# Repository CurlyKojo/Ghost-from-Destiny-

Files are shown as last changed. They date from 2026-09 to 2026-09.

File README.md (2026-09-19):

ghost

#Ghost from Destiny — a 3D-printed voice companion

A desk-sized Ghost that listens for "Hey Ghost", talks back in character, animates its eye, glows, and looks around. Alexa-shaped idea, Ghost-shaped personality.

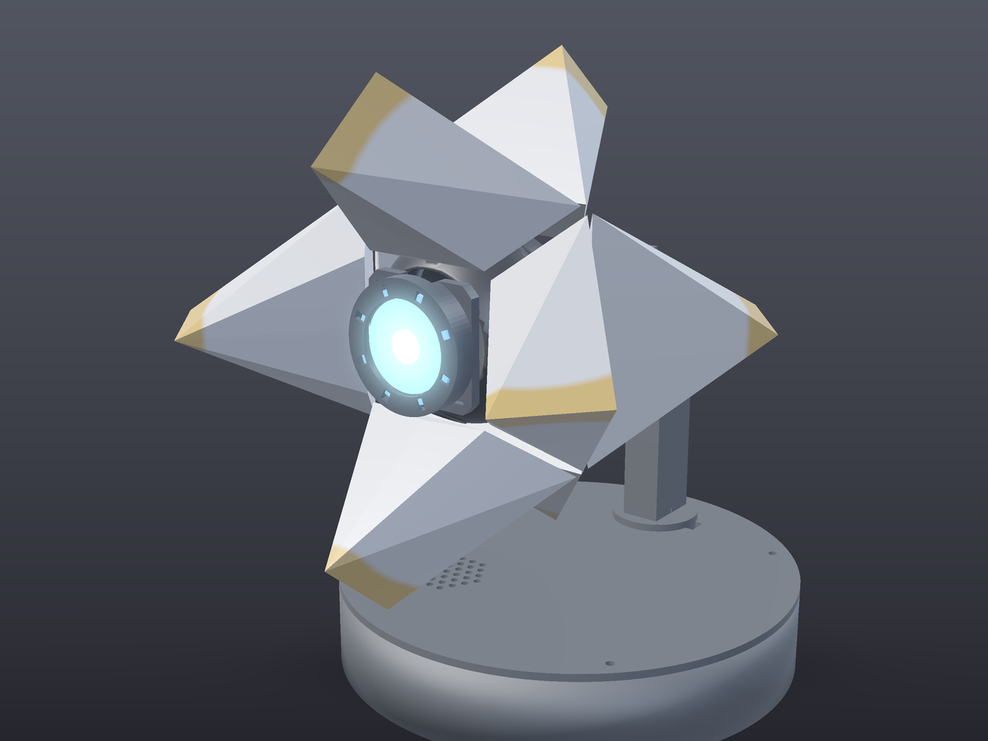
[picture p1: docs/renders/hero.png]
hero


The shell is built straight from the Bungie reference sheet: the same 8 pieces, the diamond with its X seams from the front, the X with blunt arm ends from the side, the central diamond and notches from the top.

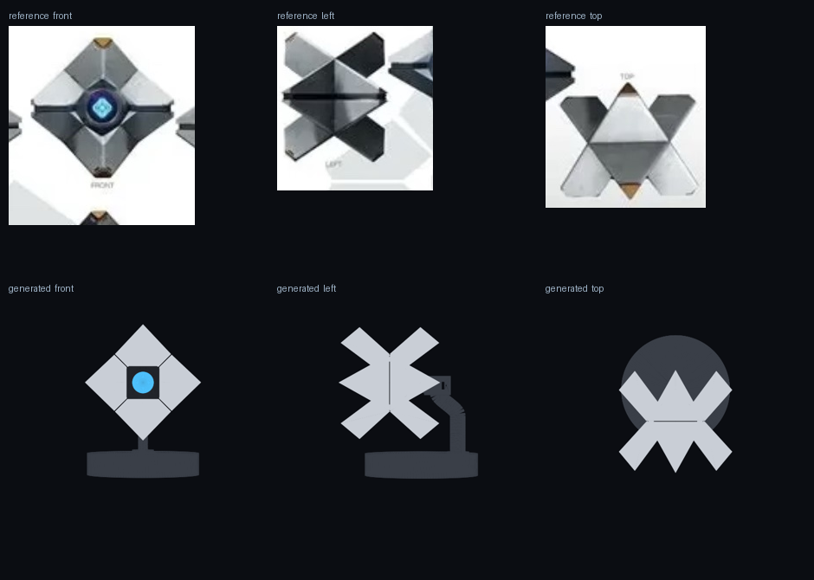
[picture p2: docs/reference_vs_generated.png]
reference vs generated


The shell opens: each piece rides a spring-loaded pin in the core, eight tendons meet at a ring on the eye axis, and a Bowden cable to a servo in the base pulls them shut.

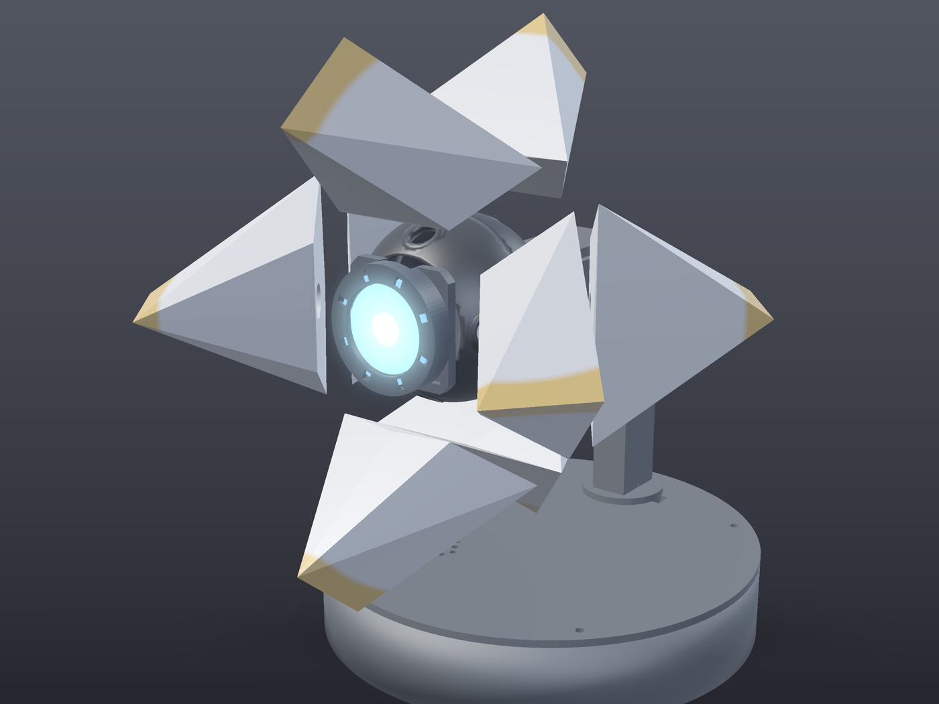
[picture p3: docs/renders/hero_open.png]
open


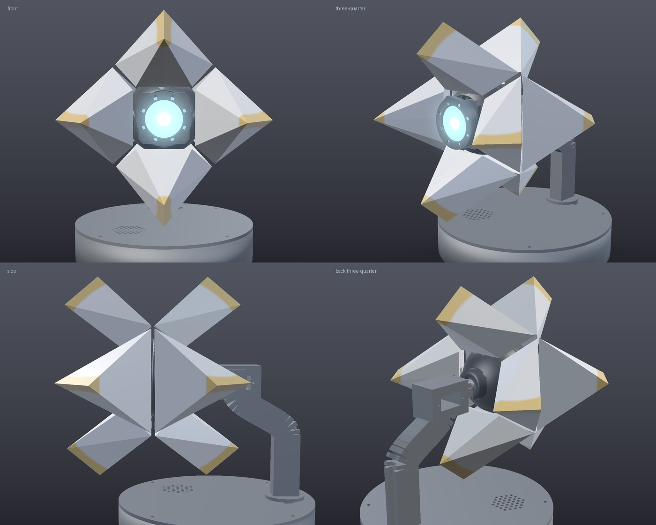
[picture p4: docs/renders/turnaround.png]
turnaround


- **Print it** — 12 STL files, ~500 g of filament, ~32 h of printing. 180 mm tip to tip closed, 200 mm open. Parametric generator included.
- **Build it** — Raspberry Pi 4, a round 1.28" LCD for the eye, I2S mic + amp, a 16-LED ring, three servos: pan, tilt, and a spool in the core that lets the shell **spread open like the in-game scan**. About $165.
- **Run it** — wake word + speech-to-text run offline on the Pi; the personality is Claude with emotion tags that drive the eye, the lights and the body; the voice is Piper with a "Ghost" filter chain.

## Repo layout

```
hardware/
  generate_stl.py      parametric generator (trimesh) - every dimension is a parameter
  stl/                 fin_x8, slider_pin_x8, spider_ring, spool, shell_servo_mount,
                       core_front, core_back, eye_bezel, arm, head_mount, base, base_lid
  preview_open.png     shell spread open
  render.py            shaded renders (numpy rasterizer, no GPU) -> docs/renders/
  preview.png          assembled render (front / side / top)
  parts.png            every part in print orientation
docs/
  01-hardware-bom.md   parts list with prices
  02-print-guide.md    settings, orientation, finishing
  03-wiring.md         pin map + wiring diagram
  04-assembly.md       step by step
  05-software-setup.md Pi setup, wake word training, troubleshooting
  06-voice-and-personality.md
software/
  ghost/               the Python package (main loop, brain, eye, lights, motion, tts, stt, wake, tools)
  tools/               preview_eye.py, chat.py, servo_calibrate.py
  install.sh           one-shot Pi setup
  ghost.service        systemd unit
  .env.example         configuration
```

## Quick start

```bash
# 1. print hardware/stl/*  (docs/02-print-guide.md)
# 2. wire it              (docs/03-wiring.md)
# 3. on the Pi:
git clone <this repo> ~/ghost && cd ~/ghost/software && bash install.sh
nano .env            # ANTHROPIC_API_KEY, your name, your city
sudo reboot && sudo systemctl start ghost
```

Then say **"Hey Ghost, what's the weather like?"**

No hardware yet? `python -m ghost.main --sim --mock` runs the whole pipeline on a laptop with a canned brain.

## How it works

```
 mic → openWakeWord → record → faster-whisper → Claude (personality + tools) → Piper + Ghost FX → speaker
                                                    │
                        [emotion] tags → eye animation (GC9A01) · LED ring · pan/tilt gestures
```

The reply streams: the first sentence is spoken while the rest is still being written, and every `[happy]`, `[curious]`, `[worried]` tag in the stream changes the eye, the ring colour and the body language. Local tools handle time, timers, weather, volume and (optionally) Home Assistant.

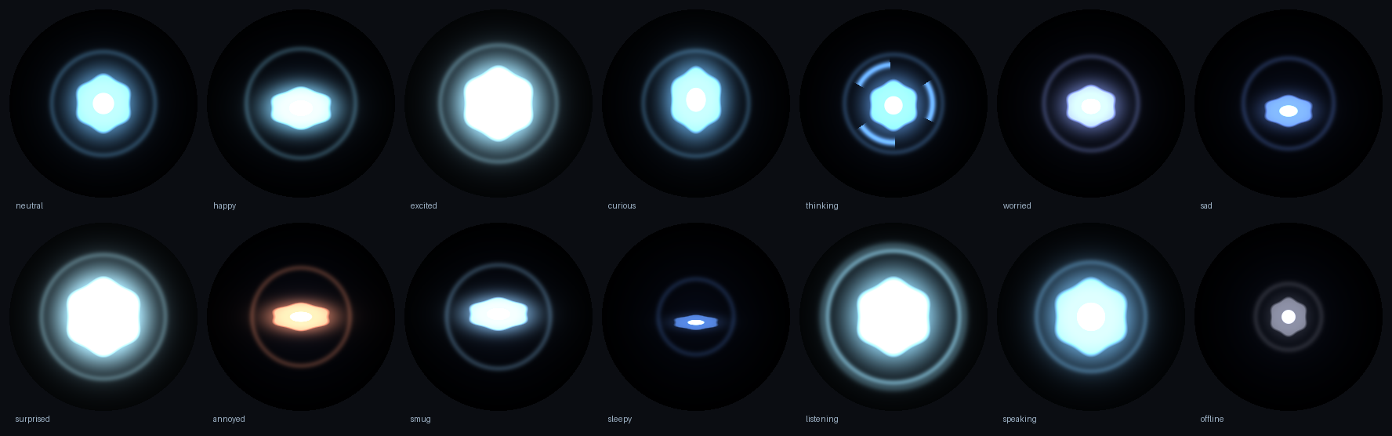
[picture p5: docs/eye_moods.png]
eye moods


## Regenerating the STLs

```bash
pip install trimesh manifold3d numpy scipy shapely matplotlib
python3 hardware/generate_stl.py            # writes hardware/stl + previews, checks for collisions
python3 hardware/generate_stl.py --scale 0.95   # a slightly smaller Ghost
```

The generator also verifies that the shell pieces don't intersect each other, the core or the eye bezel, and that the head clears the arm through ±15° of tilt (the software's limit).

## Notes

- Destiny and the Ghost are Bungie's. This is a fan project; nothing here is affiliated with or endorsed by Bungie.
- The voice is a stock TTS voice with processing, not a clone of the game's voice actor.
- `docs/05-software-setup.md` explains the Pi 5 caveat (NeoPixel driver) and the 30-minute custom wake word training.

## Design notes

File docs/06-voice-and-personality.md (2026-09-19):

# 06 · Voice and personality

## Voice

The game's Ghost is voiced by an actor, and cloning a real person's voice without permission isn't something this project does. What we do instead gets close to the character's *feel*: a warm, slightly boyish male voice with a clean, faintly synthetic edge.

**Default: Piper (offline)** with the `en_US-ryan-medium` voice, then the Ghost filter chain in `ghost/tts.py`:

1. a small pitch lift (`GHOST_VOICE_PITCH=1.06`, try 1.03–1.10)
2. high-pass at 140 Hz (small body, no chest resonance)
3. presence boost around 2.8 kHz and a little sheen at 5 kHz
4. a 9 ms metallic slap delay
5. a soft limiter

Turn the filter off with `GHOST_VOICE_FX=false` to hear the raw voice. Other Piper voices worth trying (download from https://huggingface.co/rhasspy/piper-voices, set `PIPER_MODEL`): `en_US-joe-medium` (darker), `en_US-lessac-medium` (neutral), `en_GB-alan-medium` (British, oddly Ghost-ish).

`PIPER_LENGTH=0.95` makes him talk a touch faster; 1.05 slower.

**Optional: ElevenLabs (cloud).** Better prosody, ~300 ms extra latency, costs money. Design a voice in their Voice Design tool that sounds like a chipper, earnest robot companion, then:

```
GHOST_TTS=elevenlabs
ELEVENLABS_API_KEY=...
ELEVENLABS_VOICE_ID=...
```

The Ghost filter still runs on top unless you turn it off.

## Personality

All of it is in `software/ghost/personality.py`. The system prompt tells Claude who the Ghost is, how to speak for TTS (short, no lists, numbers in words), and how to use the **emotion tags**.

Every reply starts with a tag like `[curious]` and may change mid-reply. The tags are stripped before speech and drive:

| tag | eye | LED ring | head | shell |
|---|---|---|---|---|
| neutral | steady blue, slow breathing, blinks | soft glow | idle drift | closed |
| happy | squashed "smile" | brighter | bounce | 40 % |
| excited | big and bright | pulsing | wiggle | open |
| curious | tall, tilted | steady | head tilt | half |
| thinking | spinner arcs | chasing light | look up | open (scanning) |
| worried | small, purple-blue | dim | shrink back | closed |
| sad | dim, drooping | dark blue | droop | closed |
| surprised | wide, white | flash | recoil | open |
| annoyed | narrow, orange | orange | head shake | closed |
| smug | half-lidded | steady | tilt | 30 % |
| sleepy | thin line | very dim | droop | closed |
| listening | bright, rippling | pulsing | lean in | 60 % |

Waking to "Hey Ghost" also fires the **scan flare**: the shell snaps fully open for half a second and settles back.

eye moods

Add a mood: put it in `EMOTIONS`, give it a row in `MOODS` (`eye.py`), `COLORS` (`lights.py`) and the table in `Body.mood()` (`motion.py`).

## Model

`GHOST_MODEL=claude-opus-5` at `GHOST_EFFORT=low` is the default: it keeps replies snappy while staying in character. Raise effort to `medium` if you want him to think harder about real questions. Refusal fallback (`GHOST_FALLBACKS=true`) is on by default, which means that if the model declines something for policy reasons the API retries on a fallback model inside the same call; the Ghost still says its canned refusal line if the whole chain declines.

The conversation is kept for 12 turns and forgotten after 20 minutes of silence, or when you say "forget everything".

## Tools (what he can *do*)

`ghost/tools.py`:

| tool | what |
|---|---|
| `get_time` | date/time/day |
| `set_timer` / `cancel_timer` / `list_timers` | countdown timers; he announces them when they fire |
| `get_weather` | Open-Meteo, no key needed |
| `set_volume` | 0–100 |
| `home_assistant` | any HA service call, only offered when `HA_URL` + `HA_TOKEN` are set |

Adding one: append a schema to `definitions()`, a branch in `run()`, done. The validator reads the schema. Keep inputs flat (strings, integers, one object) because the inputs stream in eagerly and the Ghost validates them itself.

## Things he says on his own

- Wake with no speech: a short ack ("Guardian?") and a 6-second follow-up window.
- Timer firing: chime + one of the `TIMER_LINES`.
- API down: one of the `OFFLINE_LINES` ("I've lost my link to the Tower").

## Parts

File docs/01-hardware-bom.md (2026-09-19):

# 01 · Bill of materials

Reference build: **Raspberry Pi 4** in the base, everything else in the head, one ribbon up the arm.
Prices are typical 2026 US street prices. Total is roughly **$140–170** plus filament.

## Electronics

| # | Part | Qty | ~Price | Notes |
|---|---|-----|---|---|
| 1 | Raspberry Pi 4 Model B, 2 GB (4 GB is nicer) | 1 | $45–55 | Pi 5 works too but see the LED note in [05-software-setup](05-software-setup.md#raspberry-pi-5) |
| 2 | microSD card, 32 GB, A1/A2 | 1 | $8 | |
| 3 | 5 V 5 A power supply, 5.5×2.1 mm barrel | 1 | $12 | One supply feeds Pi + servos + LEDs + amp |
| 4 | Panel-mount 5.5×2.1 mm DC jack | 1 | $3 | Fits the 8 mm hole in the base wall |
| 5 | 1.28" round IPS LCD, **GC9A01**, 240×240, SPI (Waveshare "1.28inch LCD Module" or clone) | 1 | $15 | The eye. 36.5 mm square PCB, 32.4 mm active area |
| 6 | **MAX98357A** I2S 3 W amplifier breakout | 1 | $6 | Adafruit or clone |
| 7 | Speaker, 40 mm, 4 Ω, 3 W | 1 | $5 | Sits under the grille in the base lid |
| 8 | **INMP441** I2S MEMS microphone breakout | 1 | $5 | Mounted in the head behind the vent holes |
| 9 | NeoPixel / WS2812B ring, **16 LEDs, 44 mm OD** | 1 | $8 | Glows through the eye bezel |
| 10 | **PCA9685** 16-channel PWM servo driver (I2C) | 1 | $6 | Jitter-free servos, works on any Pi |
| 11 | **MG90S** metal-gear micro servo | 3 | $12 | Pan, tilt, and the shell spool in the base. SG90 fits the same pockets but strips faster |
| 11a | Compression springs, **12 mm OD × 25 mm free length, 0.4–0.5 mm wire** | 8 | $6 | Push the shell open. A cheap assortment box has them |
| 11b | Braided fishing line, 20–30 lb | 2 m | $5 | The eight tendons inside the core |
| 11c | PTFE Bowden tube, **2 mm ID / 4 mm OD** | 0.5 m | $3 | 3D-printer Bowden tube. Sheath from the base up to the core |
| 11d | Bowden inner wire: 1 mm stainless wire or 0.8 mm braided line | 0.5 m | $2 | Runs inside the sheath, pulls the spider ring |
| 12 | 74AHCT125 level shifter | 1 | $2 | Optional but recommended for the LED data line |
| 13 | 1000 µF ≥6.3 V electrolytic capacitor | 1 | $1 | Across 5 V/GND at the LED ring |
| 14 | 470 Ω resistor | 1 | — | In series with LED data |
| 15 | 2-position screw terminal or Wago for 5 V distribution | 1 | $2 | |

## Wire and connectors

| Part | Qty | Notes |
|---|-----|---|
| 26–28 AWG silicone wire, assorted colours | ~5 m | Or a 16-way ribbon cable for the arm run |
| Dupont / JST-XH connectors + crimper | — | Makes the head detachable |
| 2.54 mm female header for the Pi GPIO | 1 | Or a GPIO breakout / "cobbler" |

## Fasteners and misc.

| Part | Qty | Used for |
|---|-----|---|
| M2 × 6 mm self-tapping screws | 12 | Core halves (3), servo tabs (4), servo horns (3), spool to horn (1) |
| M2.5 × 6 mm screws | 4 | Pi to the standoffs in the base |
| M3 × 10 mm screws | 4 | Base lid |
| Servo horn screws (come with the servos) | — | |
| CA glue (super glue) + hot glue | — | Shell pieces to pegs, bezel, LED ring |
| Double-sided foam tape | — | Display, mic, amp |
| Sandpaper 220/400, filler primer, paint (see print guide) | — | Optional finish |

## Filament

About **500 g** total.

| Colour | Parts | ~Grams |
|---|---|---|
| Silver / light grey PLA or PETG | 8 × shell piece | 240 |
| Any (hidden) | 8 × slider pin, spider ring, spool, shell servo mount | 45 |
| Black or dark grey | core_front, core_back, arm, head_mount, base, base_lid | 215 |
| White or natural/translucent | eye_bezel | 8 |

## Optional upgrades

- **Clear lens**: a 33 mm clear acrylic disc (1–2 mm) in front of the display looks great and protects the glass.
- **Bigger speaker**: a 50 mm 4 Ω driver fits if you scale the base radius in `hardware/generate_stl.py` (`base_r`).
- **ReSpeaker 2-Mic HAT** instead of the INMP441 + MAX98357A: it has both mic and amp on one HAT. You lose the head-mounted mic (it sits on the Pi in the base) but the setup is one overlay.
- **Pi Zero 2 W** in the base works for the eye/LEDs/servos, but Whisper speech-to-text will be slow (5–8 s). Keep the Pi 4 unless you move STT to the cloud.

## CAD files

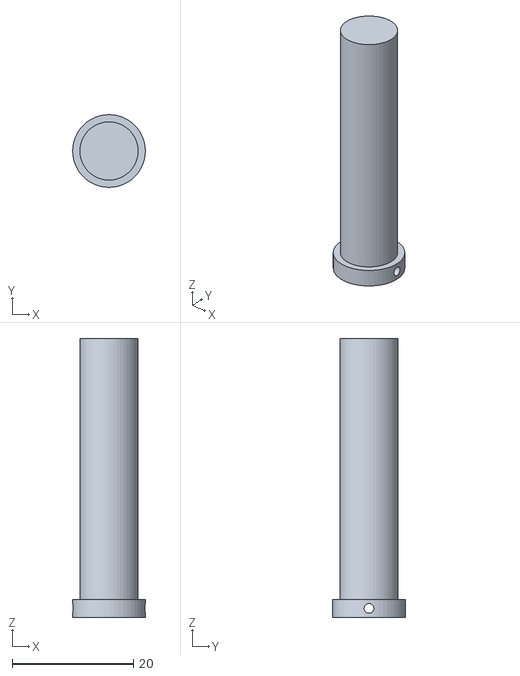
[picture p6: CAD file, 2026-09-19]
hardware/stl/slider_pin_x8.stl
12.0 x 12.0 x 46.0

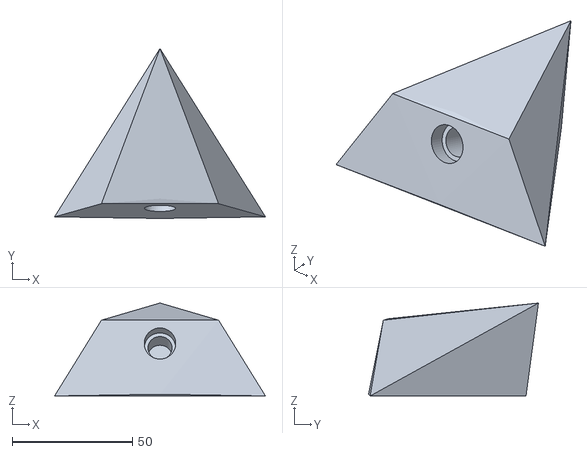
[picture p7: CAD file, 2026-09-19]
hardware/stl/fin_x8.stl
87.8 x 70.7 x 38.7

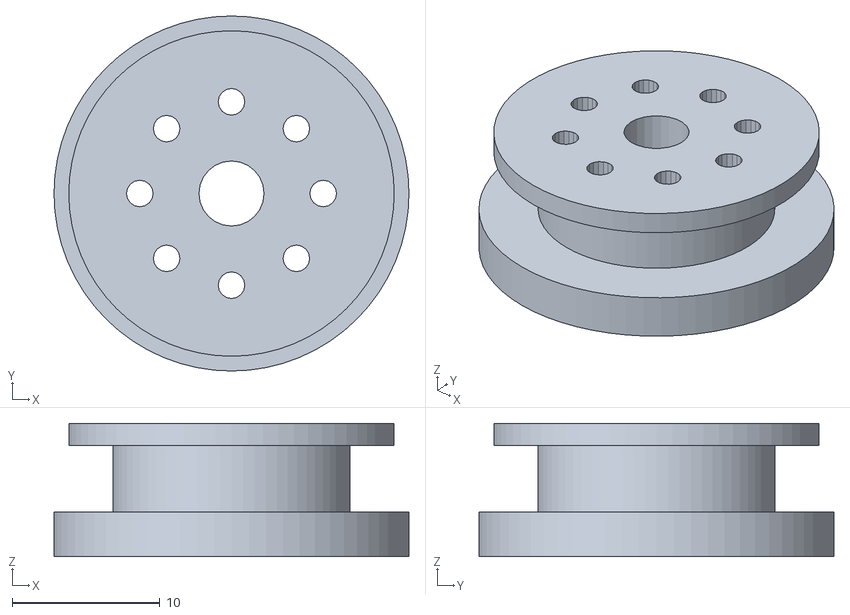
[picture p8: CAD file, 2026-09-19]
hardware/stl/spool.stl
24.0 x 24.0 x 9.00

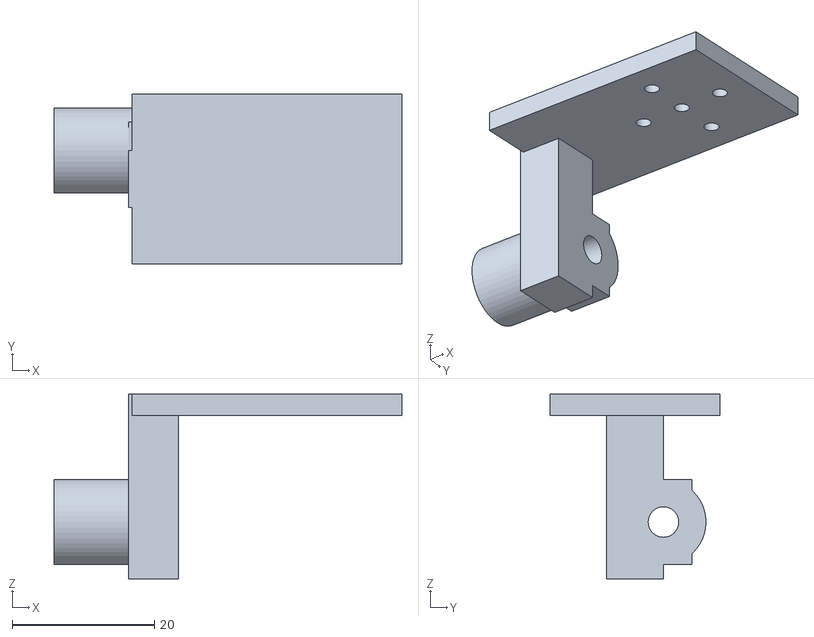
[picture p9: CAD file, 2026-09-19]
hardware/stl/head_mount.stl
49.0 x 24.0 x 26.0

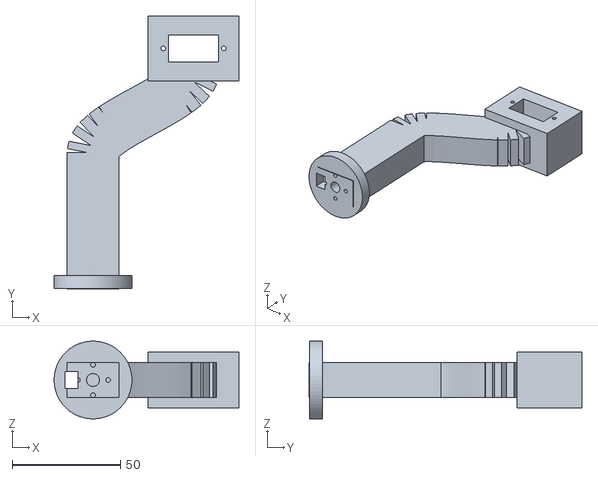
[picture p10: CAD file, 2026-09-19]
hardware/stl/arm.stl
85.5 x 126.3 x 36.0

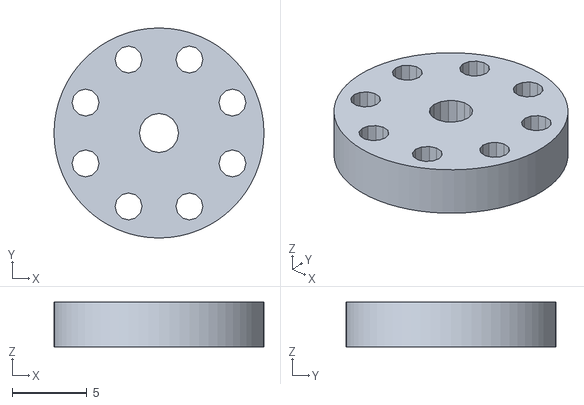
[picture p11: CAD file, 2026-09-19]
hardware/stl/spider_ring.stl
14.0 x 14.0 x 3.00

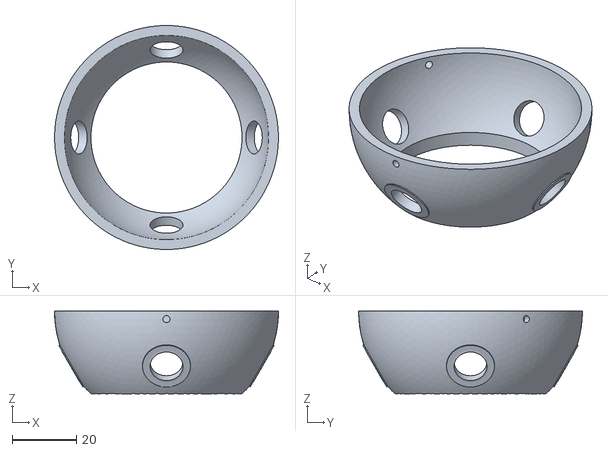
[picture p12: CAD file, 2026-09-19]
hardware/stl/core_front.stl
70.0 x 70.0 x 25.9

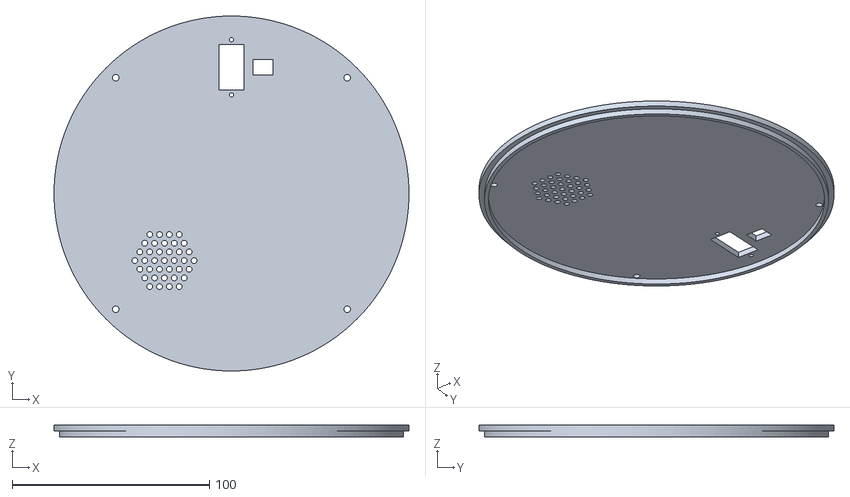
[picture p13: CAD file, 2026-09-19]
hardware/stl/base_lid.stl
180.0 x 180.0 x 6.00

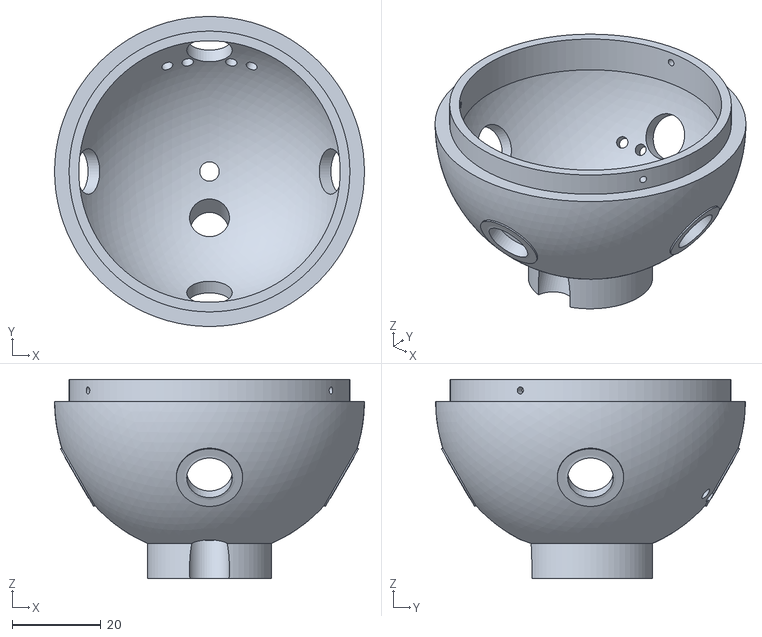
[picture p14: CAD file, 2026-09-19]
hardware/stl/core_back.stl
70.0 x 70.0 x 45.0

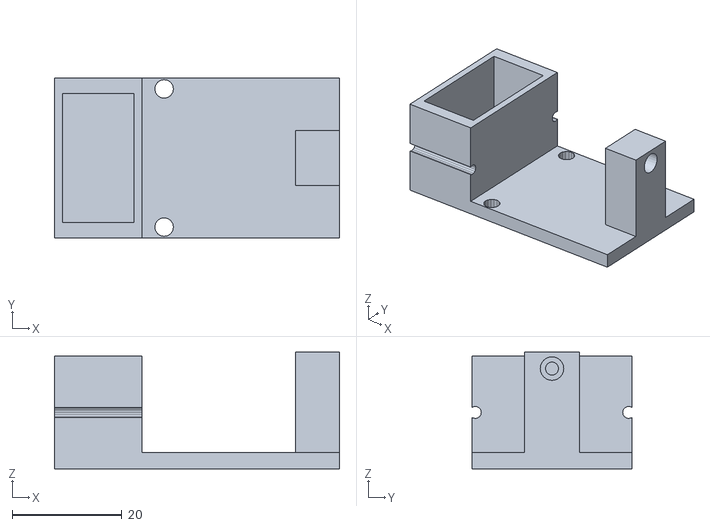
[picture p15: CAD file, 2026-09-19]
hardware/stl/shell_servo_mount.stl
52.0 x 29.2 x 21.3

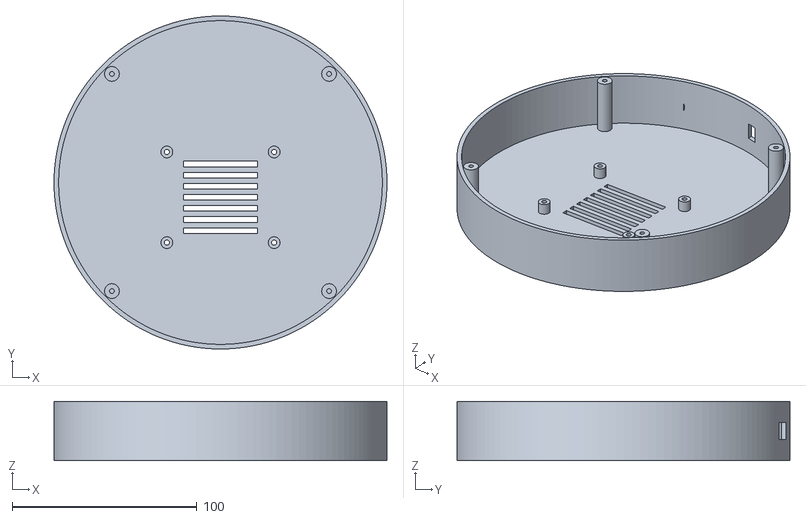
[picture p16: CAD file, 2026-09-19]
hardware/stl/base.stl
180.0 x 180.0 x 32.0

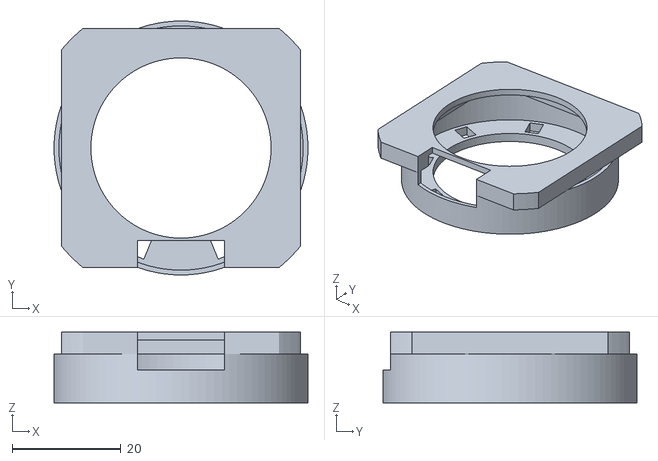
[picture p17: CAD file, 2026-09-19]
hardware/stl/eye_bezel.stl
46.8 x 46.8 x 13.0

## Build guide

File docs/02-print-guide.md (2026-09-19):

# 02 · Printing

All parts are generated by `hardware/generate_stl.py` and live in `hardware/stl/`. Re-run the script to change any dimension (every number is a parameter at the top of the file).

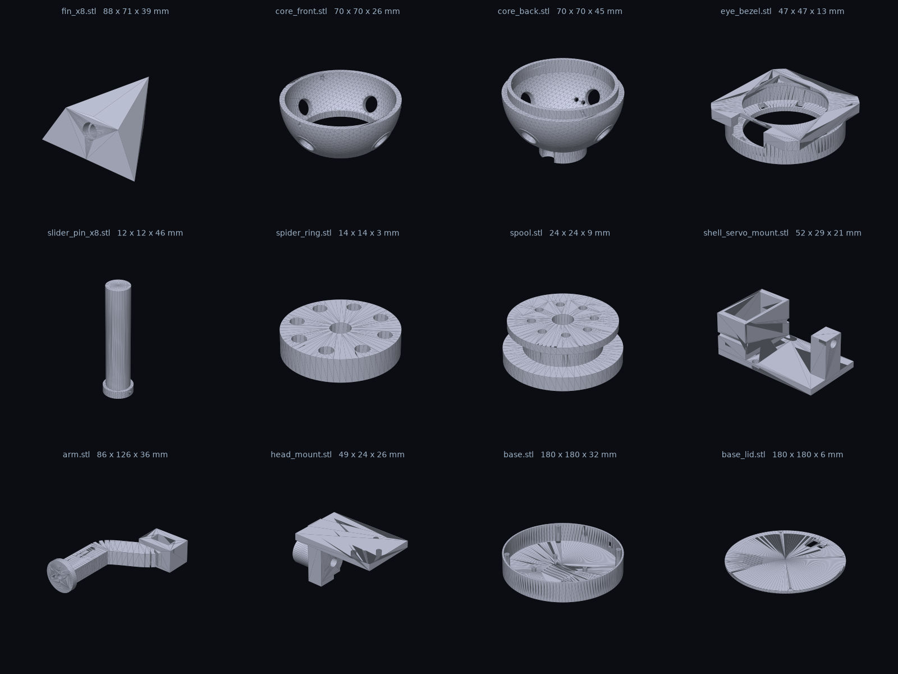
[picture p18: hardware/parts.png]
parts


## Parts list

| File | Print | Material | Orientation | Supports | Infill | Time (0.2 mm) |
|---|---|---|---|---|---|---|
| `fin_x8.stl` | **×8** | silver | as exported: largest flat face down | build-plate-only supports | 15 % | ~2 h each |
| `core_front.stl` | 1 | black | as exported: cut face down, eye bore up | no | 20 % | ~2.5 h |
| `core_back.stl` | 1 | black | as exported: cut face down, lip up | small supports under the neck pad and pegs help | 20 % | ~3 h |
| `eye_bezel.stl` | 1 | white / translucent | as exported: lens lip down | no | 100 % | 25 min |
| `slider_pin_x8.stl` | **×8** | any | as exported: cap down, vertical | no | 100 %, 4 walls | 20 min each |
| `spider_ring.stl` | 1 | any | as exported | no | 100 % | 5 min |
| `spool.stl` | 1 | any | as exported | no | 100 % | 15 min |
| `shell_servo_mount.stl` | 1 | black | as exported: foot down | no | 40 % | 45 min |
| `arm.stl` | 1 | black | as exported: on its side | yes, for the servo pocket and the bend | 40 %, 4 walls | ~3.5 h |
| `head_mount.stl` | 1 | black | as exported | yes | 60 %, 4 walls | 40 min |
| `base.stl` | 1 | black | as exported: floor down | no | 15 % | ~6 h |
| `base_lid.stl` | 1 | black | as exported: top face down | no | 20 % | ~2 h |

Total print time is about **32 h** on a 0.4 mm nozzle. The shell pieces are 88 × 71 × 39 mm each and look great in a silk silver.

## Settings that matter

- **Layer height** 0.2 mm (0.16 for the fins if you want crisp tips).
- **Walls** 3 (4 on the arm and head_mount, they carry the head).
- **Tolerances** are built in: pegs are 10 mm Ø into 10.8 mm sockets; the bezel is 46.8 mm into a 47.2 mm bore; the core lip is 0.6 mm smaller than the front cavity. If your printer runs tight, sand the pegs; if loose, a drop of CA glue fixes everything.
- **Shell pieces**: each is a convex solid with a 40 mm blunt tip edge, two wings and three inner corners. It rests on its largest face; two of the other faces lean past 45°, so enable supports touching the build plate only. The socket is a 10 mm hole for the slider pin (glue fit) behind a 13 mm × 6 mm counterbore that swallows the compressed spring, so the closed shell keeps the reference's tight seams.
- **Slider pins**: 9.6 mm pins that run in the core's 10.3 mm guide tubes. Print them slow and clean, then sand lightly with 400 grit until they slide freely with no wobble. A dab of silicone grease helps.
- **Core halves**: the guide tubes are printed in; poke a 10 mm drill or a pin through each bore to clear any sag. The 4.4 mm hole in the neck socket is for the Bowden wire.
- **Head mount**: printed with a 4.3 mm bore straight through for the PTFE tube. Run a 4 mm drill through it after printing.
- **Core halves**: the sphere is a 3 mm shell. Print with a brim; the flat cut face gives plenty of adhesion.
- **Base**: nothing fancy. The vent slots and Pi standoffs are on the floor.

## Finishing (optional, but it's what makes it look like *the* Ghost)

1. Sand the fins' flat front faces to 400 grit. Everything else can stay as printed.
2. Two light coats of filler primer, sand at 400.
3. Fins: a bright silver or "aluminium" metallic. The reference sheet shows warm brass/gold **tips** on the fins: mask the outer 8 mm and hit them with a gold or copper metallic.
4. Core, arm, base: matte black or gunmetal.
5. Bezel: leave it white. The LED ring lights it from behind.
6. A satin clear coat over everything.

## Scaling

`python3 hardware/generate_stl.py --scale 0.95` shrinks the shell and core (the stand and base stay the same). Below about 0.95 the 36.5 mm display PCB no longer fits inside the sphere, so for a smaller Ghost swap in a 0.96" or 1.14" display and shrink `eye_bore_r` / `bezel_*` too.

## How the shell geometry was derived

reference vs generated

Each of the 8 pieces is the convex hull of six kinds of points read off the reference sheet, defined in `piece_points()`:

- a **blunt tip edge** (40 mm) so the tip is a point from the front but a flat end from the side, like the arms of the X on the sheet;
- two **wings** on the diamond's edge midpoints, on the mid-plane, where four pieces meet; they give the solid diamond from the front and the central diamond + notch pattern from the top and side;
- two **inner corners on the diagonals** at the eye ring, shared with the neighbouring pieces so the front shows thin X seams from the eye to the edge midpoints;
- an **inner-front corner** where the ridge (the crease down the middle of each piece) ends beside the eye bezel, and an **inner-back corner** on the seam plane.

The top-front piece is built once; the other seven are 90° rotations about the eye axis and a front/back mirror. Every dimension is a parameter at the top of the generator.

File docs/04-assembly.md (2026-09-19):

# 04 · Assembly

Read [03-wiring](03-wiring.md) first and pre-wire the head modules with 40 cm leads before anything goes in the sphere.

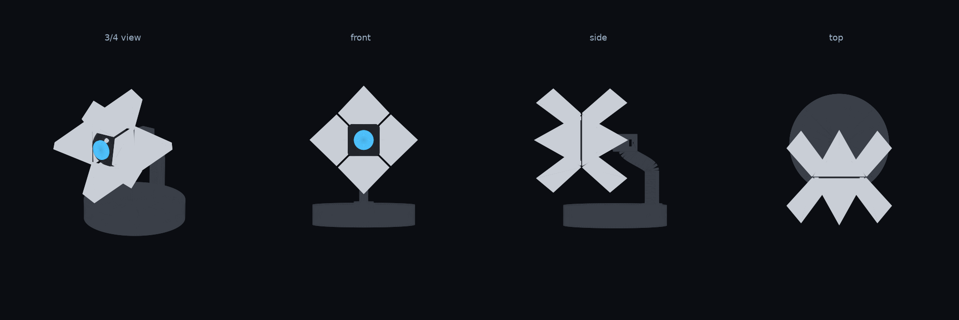
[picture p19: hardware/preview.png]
assembled


## 1. Eye stack (bezel)

1. Press the **NeoPixel ring** into the pocket behind the bezel lip, LEDs facing the lip. The ring's solder pads face the slot marked for the FPC. A dab of hot glue on the back holds it.
2. Set the **display** glass-down into the tube behind the ring, then the PCB into the square pocket of the backplate. Route the FPC/header out the notch. Tape it.
3. Optional: 33 mm clear acrylic disc glued into the lip window.
4. Test now: `GHOST_DISPLAY=gc9a01 python -m ghost.main --sim --mock` on the Pi with the display wired. If you see the eye, keep going.

## 2. Core

1. Slide the bezel into the front hemisphere's bore from the inside. Friction fit; CA glue the rim.
2. Stick the **INMP441** to the inside of the back hemisphere right behind the four vent holes on top (foam tape). The holes are the mic's acoustic port.
3. Feed all leads out the cable hole beside the neck pad.
4. Mate the halves: the back half's lip goes into the front half. Three M2 screws through the front half into the pilot holes in the lip (or CA glue if you never want to open it).

## 3. The spreading shell

How it works: every piece is glued to a **slider pin** that runs through a guide tube in the core. A **spring** on the pin, trapped between the core surface and the piece, pushes the piece out. A **fishing-line tendon** tied to the cap on the pin's inner end runs to a small **spider ring** on the eye axis inside the core. A **Bowden cable** (PTFE tube + wire) runs from that ring out through the hollow neck, down the arm, to a **spool** on a servo in the base. Wind the spool and the ring pulls all eight tendons: the pieces slide in against the springs (closed, the normal look). Unwind and the springs spread the shell open, the pieces separating along their own axes like the in-game scan. The generator solves the ring geometry so the front and back groups close together: the ring travels 10 mm, front tendons are 28 mm and back tendons 16 mm (cap centre to ring hole).

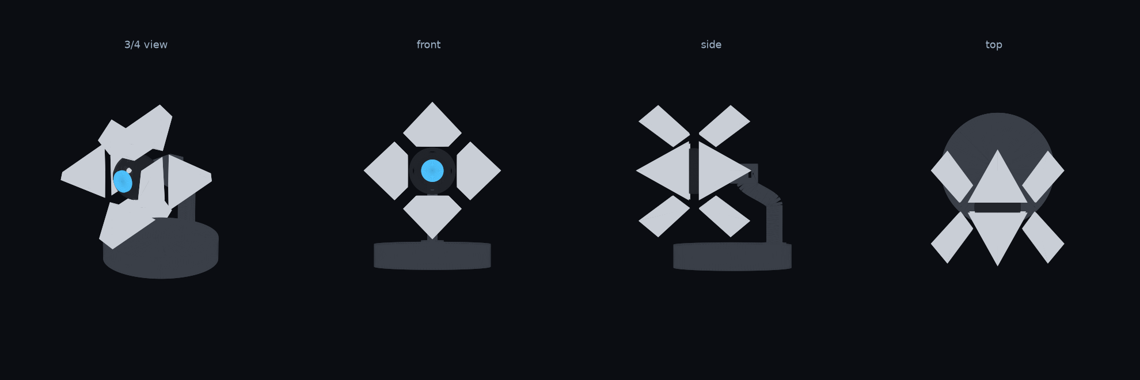
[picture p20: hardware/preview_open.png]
open


Do this **before** joining the core halves:

1. Push the 8 **slider pins** through the guide tubes **from the inside**, caps inward. The caps stop against the tubes so the pins can't fall out.
2. Crimp or knot the Bowden **wire** through the centre hole of the **spider ring**, then feed the wire out through the 4.4 mm hole in the neck socket at the back of `core_back`.
3. Tie the tendons. With every pin pushed fully out (open) and the ring held 11 mm behind the core centre (a mark on the wire helps: the generator's `ring_travel()` gives the exact numbers), tie a line from each cap hole to a ring hole: the **front four at 28 mm**, the **back four at 16 mm**, cap centre to ring hole, plus a hair of slack. Braided line and a drop of CA on each knot.
4. Pull the wire 10 mm: every pin should slide in flush. If one lags, re-tie it a touch shorter.
5. Join the core halves (section 2, step 4). The ring floats on its eight tendons; it needs no guide.
6. Feed the **PTFE tube** through the head mount's bore into the neck socket until it seats against the core, then thread the wire through the tube. The tube runs down the arm's channel with the ribbon, through the lid slot, to the `shell_servo_mount` in the base.
7. In the base: screw the 20 mm round horn to the **spool**, fit the spool on the **shell servo**, drop the servo into the mount's cradle (shaft along the mount), and seat the tube's end in the post. Set the servo to the open angle (`tools/servo_calibrate.py`, channel 2), pull the wire snug through the spool's hole and tie it off. Winding the servo to the closed angle (about 140° of travel on an 8 mm spool is 20 mm, more than the 10 mm needed) closes the shell; `GHOST_SHELL_CLOSED` is wherever the pieces are just snug.

## 4. Pieces

1. Slide a **spring** over each pin from the outside, then test-fit a piece: the socket is 10 mm for the 9.6 mm pin, and the 6 mm deep counterbore swallows the spring when closed (only 3 mm of gap shows). Sand the pin if tight.
2. All 8 pieces are identical. Orientation, for a front piece: the **blunt tip edge points outward**, the **ridge (crease) faces the front**, and the two **wings sit on the mid-plane** (level with the core's equator seam, one each side). The two short inner edges frame the eye. Back pieces are the same with the ridge facing backward. With the shell closed, neighbouring pieces should nearly touch along the diagonal edges from the eye ring to the wings.
3. Sight down the assembled Ghost against `docs/reference_vs_generated.png`: from the front a clean diamond with thin X seams, from the side an X with blunt arm ends, from the top the central diamond with a notch on each side.
4. CA glue each piece onto its pin with the shell **closed** (wire pulled) so the closed look is the tight one. Let it cure before releasing.
5. Release the servo: the shell should spring open about 12 mm on every piece and pull shut cleanly. If a piece sticks, its pin needs more sanding or grease.

## 5. Stand

1. Drop the **pan servo** into the pocket in the lid, shaft up, two M2 screws through the tabs from underneath. Centre it (`tools/servo_calibrate.py`, or just power it and set 90°).
2. Screw a round servo horn to the bottom disc of the **arm** (4 holes at 7 mm radius), then press the horn onto the pan servo shaft with the arm pointing straight back and secure with the horn screw.
3. Press the **tilt servo** into the pocket at the top of the arm, shaft toward +x (the side with the open face), screws through the tabs along x.
4. Fit a single-arm horn to the **head_mount** plate (3 holes) and mount it on the tilt servo at 90°.
5. Head goes on: the head_mount's round stub plugs into the socket on the core's neck pad. CA glue once you're happy with the angle (level, eye straight ahead).

## 6. Base electronics

1. Pi on the four standoffs (M2.5). USB/HDMI toward the slot in the rear wall.
2. DC jack in the 8 mm hole. Terminal block next to it.
3. Speaker under the lid grille (hot glue or tape), MAX98357A next to it.
4. PCA9685 anywhere it fits; short leads to the servos.
5. Route the head ribbon through the lid slot beside the pan servo, down the back of the arm's channel, and leave the service loop at the top.
6. Lid on, four M3 screws.

## 7. First power-up checklist

- [ ] `sudo i2cdetect -y 1` shows `40` (PCA9685)
- [ ] `aplay -l` shows the voice HAT card; `speaker-test -c1 -t sine` makes noise
- [ ] `arecord -d 3 -f S16_LE -r 16000 test.wav && aplay test.wav` plays your voice
- [ ] `python -m ghost.main --sim --mock` shows the eye, lights the ring, and the shell flares open and shut
- [ ] `.env` has the API key, then `python -m ghost.main`
- [ ] Say "Hey Ghost" (or "Hey Jarvis" until your custom wake model is in place)

## Power-off behaviour

The springs win when the servo is unpowered, so the Ghost sits with its shell open whenever it's off. The software parks it closed on shutdown; a hard power cut leaves it open. That's how the mechanism stays simple (tendons only pull). Because the servo lives in the base, pan and tilt flex the Bowden tube slightly; leave a gentle loop of tube at the tilt joint and it won't bind.

## Balance note

The head is ~350 g with the shell mechanism and the tilt pivot sits 70 mm behind the core centre. MG90S handles it, but if tilt sags, either move to an MG996R-class servo (edit `servo_body` in the generator) or add 30–40 g of weight in the back of the core (coins, hot-glued).

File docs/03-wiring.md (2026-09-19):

# 03 · Wiring

Everything hangs off the Pi 4's 40-pin header. The I2S pins (18/19/20/21) are shared by the amp and the mic, which is exactly the Google Voice HAT layout, so a stock overlay drives both. The LED ring uses GPIO12 (the other PWM0 pin) so it does not fight I2S.

```
                         ┌─────────────── HEAD (core) ───────────────┐
                         │  GC9A01 eye   INMP441 mic   NeoPixel ×16   │
                         └──────┬──────────────┬───────────┬─────────┘
                                │   ~15-wire ribbon down the arm       
   ┌────────────── BASE ────────┼──────────────┼───────────┼──────────────────────────┐
   │                            │              │           │                          │
   │  5V 5A ──► DC jack ──► terminal block ──► Pi 5V pin 2 + GND pin 6                │
   │                              │  ├────────► PCA9685 V+ (servo power)              │
   │                              │  ├────────► NeoPixel 5V  (+1000 µF cap)           │
   │                              │  └────────► MAX98357A VIN                        │
   │                                                                                  │
   │  Pi 4 ── SPI0 ──► display      Pi 4 ── I2S ──► MAX98357A ──► 40 mm speaker       │
   │       ── I2S  ◄── INMP441             ── I2C ──► PCA9685 ──► pan servo, tilt servo│
   │       ── GPIO12 ─(470 Ω / 74AHCT125)─► NeoPixel DIN                              │
   └──────────────────────────────────────────────────────────────────────────────────┘
```

## Pin map

| Module pin | Pi pin (BCM) | Header pin | Notes |
|---|---|---|---|
| **GC9A01 display** | | | SPI0 |
| VCC | 3.3 V | 1 | |
| GND | GND | 9 | |
| DIN (MOSI) | GPIO10 | 19 | |
| CLK (SCLK) | GPIO11 | 23 | |
| CS | GPIO8 (CE0) | 24 | |
| DC | GPIO25 | 22 | `GHOST_DISPLAY_DC` |
| RST | GPIO27 | 13 | `GHOST_DISPLAY_RST` |
| BL | GPIO24 | 18 | `GHOST_DISPLAY_BL` (or tie to 3.3 V to save a wire) |
| **MAX98357A amp** | | | I2S out |
| VIN | 5 V | 2 | from the terminal block |
| GND | GND | 6 | |
| BCLK | GPIO18 | 12 | shared with mic SCK |
| LRC | GPIO19 | 35 | shared with mic WS |
| DIN | GPIO21 | 40 | |
| GAIN | leave open | | 9 dB. Tie to GND for 12 dB if it's too quiet |
| SD | leave open | | |
| **INMP441 mic** | | | I2S in |
| VDD | 3.3 V | 17 | |
| GND | GND | 25 | |
| SCK | GPIO18 | 12 | |
| WS | GPIO19 | 35 | |
| SD | GPIO20 | 38 | |
| L/R | GND | | left channel |
| **NeoPixel ring** | | | |
| 5 V | 5 V rail | | 1000 µF cap across 5 V/GND at the ring |
| GND | GND | | |
| DIN | GPIO12 | 32 | through 470 Ω (and ideally a 74AHCT125 to make it 5 V logic) |
| **PCA9685** | | | I2C |
| VCC | 3.3 V | 1 | logic |
| SDA | GPIO2 | 3 | |
| SCL | GPIO3 | 5 | |
| GND | GND | | |
| V+ | 5 V rail | | **servo power from the supply, not the Pi** |
| ch 0 | pan servo | | `GHOST_SERVO_PAN` |
| ch 1 | tilt servo | | `GHOST_SERVO_TILT` |
| ch 2 | shell spool servo (in the base, on `shell_servo_mount`) | | `GHOST_SERVO_SHELL` |

Everything shares one ground.

## Powering the Pi from the header

Feeding 5 V into header pins 2/4 bypasses the Pi's USB-C input protection. That's normal for embedded builds but it means **use a decent supply** and add the 1000 µF cap. If you'd rather keep the protection, use a USB-C pigtail from the terminal block into the Pi's USB-C port instead.

## The ribbon up the arm

Wires that must reach the head (share the power/ground lines):

| Signal | Count |
|---|---|
| 3.3 V, 5 V, GND | 3 |
| Display: MOSI, SCLK, CS, DC, RST, BL | 6 (5 if BL is tied to 3.3 V) |
| Mic: SCK, WS, SD | 3 |
| LED: DIN | 1 |
| **Total** | **13** |

Plus the 4 mm Bowden tube for the shell, which runs alongside the ribbon in the arm channel and through the head mount into the core.

A 16-way ribbon or a bundle of 28 AWG silicone wire fits the 8×6 mm channel down the back of the arm and the 10 mm cable slot in the lid. Leave a 60 mm service loop at the tilt joint so the head can move.

## I2S overlay

`install.sh` adds this to `/boot/firmware/config.txt`:

```
dtparam=audio=off
dtoverlay=googlevoicehat-soundcard
```

That single overlay exposes the MAX98357A as playback and the INMP441 as capture on `hw:0,0`. Check with `aplay -l` and `arecord -l` after a reboot.

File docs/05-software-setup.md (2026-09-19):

# 05 · Software setup

## What runs where

```
 mic ──► openWakeWord ("hey ghost") ──► record until silence ──► faster-whisper (STT)
                                                                        │
      speaker ◄── Ghost FX ◄── Piper TTS ◄── sentence stream ◄── Claude (personality + tools)
                                                   │
                              eye animation, LED ring, pan/tilt gestures  ◄── [emotion] tags
```

Everything except the Claude call runs **on the Pi, offline**. The Claude call is what gives the Ghost a personality and general knowledge; the tools (time, timers, weather, volume, Home Assistant) run locally.

## Install

1. Flash **Raspberry Pi OS Lite (64-bit, Bookworm)** with the Pi Imager. Set your Wi-Fi and SSH in the imager.
2. Clone and install:

   ```bash
   sudo apt-get install -y git
   git clone <this repo> ~/ghost
   cd ~/ghost/software
   bash install.sh        # ~15 min: apt, SPI/I2C/I2S, venv, Python deps, Piper voice
   ```

3. Edit `~/ghost/software/.env`:

   ```
   ANTHROPIC_API_KEY=sk-ant-...
   GHOST_GUARDIAN_NAME=Kojo      # what he calls you
   GHOST_CITY=Denver             # default city for weather
   GHOST_TZ=America/Denver
   ```

4. `sudo reboot` (activates the audio overlay), then:

   ```bash
   sudo systemctl start ghost
   journalctl -u ghost -f
   ```

## Try it without hardware

Works on a laptop too (Python 3.10+):

```bash
cd software
python3 -m venv .venv && source .venv/bin/activate
pip install anthropic numpy scipy pillow requests
python -m ghost.main --sim --mock      # canned brain, eye frames to /tmp/ghost_eye.png
python -m ghost.main --sim             # real brain, type instead of talk (needs API key)
python tools/chat.py                   # brain only, shows tool calls
python tools/preview_eye.py --live     # eye window; space cycles the moods
```

## The "Hey Ghost" wake word

openWakeWord ships with a few phrases ("hey jarvis", "alexa", "hey mycroft") and the Ghost falls back to **hey jarvis** until you give it a custom model. Training "hey ghost" takes about 30 minutes and no recordings:

1. Open openWakeWord's training notebook in Google Colab: `https://github.com/dscripka/openWakeWord` → *notebooks/automatic_model_training.ipynb* → "Open in Colab".
2. Set `target_word = "hey ghost"`, keep the defaults (it synthesizes thousands of TTS samples and trains on them). Run all cells. ~20–40 min on a free GPU.
3. Download the resulting `hey_ghost.onnx` and copy it to `software/models/hey_ghost.onnx`.
4. `sudo systemctl restart ghost`. Tune `GHOST_WAKE_THRESHOLD` (0.5 default; raise it if it false-triggers, lower it if it misses).

## Speech-to-text

`faster-whisper` **base.en** (int8) is the default: ~2 s for a short sentence on a Pi 4, good accuracy. Options:

| `GHOST_WHISPER_MODEL` | Pi 4 latency | notes |
|---|---|---|
| `tiny.en` | ~1 s | fine for short commands |
| `base.en` | ~2 s | default |
| `small.en` | ~6 s | better with accents/noise; use on a Pi 5 |

## Latency you can expect (Pi 4, base.en, Piper medium, Claude Opus 5 at low effort)

| stage | time |
|---|---|
| wake word → chime | 0.1 s |
| end of speech → transcript | 1.5–2.5 s |
| transcript → first spoken sentence | 1–2 s (streams; speech starts at the first sentence) |
| each following sentence | overlaps with playback |

## Raspberry Pi 5

Everything works except `rpi_ws281x` (the NeoPixel driver) which does not support the Pi 5's RP1 I/O chip. Options: drive the ring from SPI with `adafruit-circuitpython-neopixel-spi` (then move the display to `CE1` and set `GHOST_DISPLAY_CS=7`), or hang the ring off a $4 QT Py / Trinket over USB serial. Or just build on a Pi 4, which has plenty of headroom for this.

## Troubleshooting

- **No audio devices**: `aplay -l` / `arecord -l` must list the voice HAT card. Check `dtoverlay=googlevoicehat-soundcard` is in `/boot/firmware/config.txt` and `dtparam=audio=off`.
- **Mic level**: run `python -m ghost.main -v` and watch the RMS in the debug log; set `GHOST_VAD_THRESHOLD` a bit above the room's noise floor.
- **Display is white / blank**: check DC/RST pins and `GHOST_DISPLAY_CS`. `GHOST_DISPLAY=png` writes frames to `/tmp/ghost_eye.png` so you can separate rendering from wiring problems.
- **LEDs dead**: the service must run as root (it does), and GPIO12 must not be used by anything else. Try `GHOST_LED_BRIGHTNESS=0.6`.
- **Servos buzz at rest**: set the centres properly (`tools/servo_calibrate.py`) and make sure V+ is from the 5 V supply, not the Pi's 3.3 V.
- **"lost my link to the Tower"**: that's the Ghost telling you the API call failed. Check the key, the network, and `journalctl -u ghost`.

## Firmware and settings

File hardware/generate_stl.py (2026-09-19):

#!/usr/bin/env python3
"""
Parametric Destiny Ghost shell generator.

Produces every printable part as an STL in hardware/stl/ plus a preview render.
Everything is built in the "world" frame:  +x right, +y up, +z toward the viewer
(the eye faces +z).  Units are millimetres.

    python3 hardware/generate_stl.py            # writes hardware/stl/*.stl + preview.png
    python3 hardware/generate_stl.py --scale 0.8  # smaller Ghost

Requires:  pip install trimesh manifold3d numpy scipy shapely matplotlib
"""
from __future__ import annotations

import argparse
import math
import os
import sys

import numpy as np
import trimesh
from trimesh.creation import box, cylinder, icosphere
from trimesh.transformations import rotation_matrix, translation_matrix

# ---------------------------------------------------------------------------
# Parameters (mm).  Tweak these, re-run, re-slice.
# ---------------------------------------------------------------------------
P = dict(
    # Shell (the 8 silver pieces) -----------------------------------------
    half_w=90.0,          # half of the front-view diamond width/height (tip to tip = 180)
    half_d=75.0,          # the piece axes aim at (0, half_w, half_d): depth ~0.85 x width
    tip_w=40.0,           # length of the blunt tip edge (the arm width in the side view)
    wing_frac=0.5,        # wings sit this far along the diamond edge (0.5 = edge midpoint)
    inner_diag=(25.0, 26.0),   # (d, z): inner corners at (+-d, d, z) on the diagonals, at the eye ring
    inner_front=(26.0, 28.0),  # (y, z) of the inner-front corner on the ridge, beside the bezel
    inner_back=44.0,      # distance of the inner-back corner (on the seam plane)
    piece_gap=0.975,      # each piece scaled about its centroid -> ~2 mm seams
    # Spreading shell mechanism ---------------------------------------------
    # Each piece is glued onto a slider pin that runs in a guide tube in the core.  A
    # compression spring on the pin pushes the piece OUT; a fishing-line tendon from the
    # pin's inner cap to a spool on a servo in the core pulls it back IN.
    # The eight tendons tie to a small SPIDER RING on the eye axis inside the core.  A
    # Bowden cable (PTFE sheath + wire) runs from the ring out through the hollow neck,
    # down the arm, to a spool on a servo in the base.  Pulling the ring backward closes
    # all eight pieces at once; the generator prints the ring travel and tendon lengths.
    closed_gap=3.0,       # piece-to-core gap when closed: the reference's tight seams
    spring_seat_depth=6.0,  # counterbore inside the piece that swallows the compressed spring
    shell_travel=12.0,    # how far each piece slides out when the shell opens
    pin_r=4.8,            # slider pin
    pin_cap_r=6.0,        # cap on the pin's inner end: stop against the guide tube + tendon anchor
    pin_cap_t=3.0,
    sleeve_r=5.15,        # guide bore for the pin (0.35 mm clearance)
    sleeve_or=7.5,        # guide tube outer radius (inside the core)
    sleeve_len=6.0,       # guide tube length inward from the inner wall
    fin_socket_r=5.0,     # socket in the piece for the pin (glue fit)
    fin_socket_depth=12.0,
    spring_od=12.5,       # spring counterbore in the piece (12 mm OD spring)
    ring_r=7.0,           # spider ring
    ring_t=3.0,
    ring_tie_r=5.3,       # tendon holes on the ring
    bowden_r=2.2,         # bore for the 4 mm PTFE sheath's inner wire / sheath seat
    sheath_r=2.15,        # 4 mm OD PTFE tube (slight clearance)
    spool_r=8.0,
    spool_t=6.0,
    # Core (black sphere) ---------------------------------------------------
    core_r=35.0,
    core_wall=3.0,
    eye_bore_r=23.6,      # bore for the eye bezel tube
    lip_h=5.0,            # joining lip on the back half
    # Eye bezel -------------------------------------------------------------
    bezel_r=23.4,         # tube outer radius (0.2 mm clearance in the bore)
    bezel_len=9.0,        # tube length; the PCB backplate adds 4 mm behind it
    bezel_window_r=16.6,  # lens window (GC9A01 active area is 32.4 mm dia)
    bezel_lip_t=2.0,
    led_ring_r=22.5,      # 16-LED NeoPixel ring is 44.5 mm OD -> pocket radius
    led_ring_t=4.0,
    # Stand -----------------------------------------------------------------
    base_r=90.0,
    base_h=32.0,
    base_wall=2.5,
    base_center_z=-58.0,  # base puck centre sits this far behind the core centre
    arm_z=-122.0,         # lower arm centreline: clears the bottom-back piece, shell open, at 15 deg
    arm_w=16.0,           # arm cross-section (x)
    arm_d=24.0,           # arm cross-section (z)
    tilt_pivot_z=-70.0,   # tilt axis (parallel to x) sits here behind the core
    # Servo (MG90S / SG90 footprint) ----------------------------------------
    servo_body=(23.2, 12.6),   # slot for the body (L x W) with clearance
    servo_body_h=24.0,
    servo_hole_spacing=28.0,
    servo_hole_r=1.1,
    # Raspberry Pi 4 mounting pattern
    pi_holes=(58.0, 49.0),
    pi_hole_r=1.4,
)


# ---------------------------------------------------------------------------
# helpers
# ---------------------------------------------------------------------------
def unit(v):
    v = np.asarray(v, dtype=float)
    return v / np.linalg.norm(v)


def rot(axis, deg, point=None):
    return rotation_matrix(math.radians(deg), axis, point)


def align_z_to(direction):
    """Transform that rotates +z onto `direction`."""
    d = unit(direction)
    z = np.array([0.0, 0.0, 1.0])
    c = float(np.dot(z, d))
    if c > 0.999999:
        return np.eye(4)
    if c < -0.999999:
        return rot([1, 0, 0], 180)
    axis = np.cross(z, d)
    return rotation_matrix(math.acos(c), axis)


def cyl_along(direction, r, start, end, sections=48):
    """Cylinder of radius r along `direction` from distance `start` to `end` from origin."""
    d = unit(direction)
    length = end - start
    c = cylinder(radius=r, height=length, sections=sections)
    c.apply_translation([0, 0, start + length / 2.0])
    c.apply_transform(align_z_to(d))
    return c


def union(meshes):
    meshes = [m for m in meshes if m is not None]
    out = meshes[0]
    for m in meshes[1:]:
        out = out.union(m)
    return out


def difference(a, subtract):
    out = a
    for m in subtract:
        out = out.difference(m)
    return out


def check(mesh, name):
    if not mesh.is_watertight:
        print(f"  ! {name}: mesh is not watertight (slicers usually repair this)")
    ext = mesh.extents
    print(f"  {name:18s} {ext[0]:6.1f} x {ext[1]:6.1f} x {ext[2]:6.1f} mm   "
          f"{mesh.volume/1000:6.1f} cm3   {len(mesh.faces)} tris")
    return mesh


from trimesh.transformations import scale_matrix


def piece_points(p):
    """Corner points of the TOP-FRONT shell piece in the world frame (x right, y up, z front).

    Read straight off the reference sheet:
      A1, A2  the blunt tip edge (a point from the front, a short flat end from the side)
      W+, W-  the wings: on the diamond's edge midpoints, on the mid-plane z=0, where four
              pieces meet - they give the solid diamond outline from the front and the
              central-diamond / notch pattern from the top and side
      D+, D-  inner corners on the diagonals at the eye ring: adjacent pieces share the
              W-D edge, so the front shows thin diagonal seams from the eye to the edge midpoints
      Cf      inner-front corner on the ridge, beside the eye bezel
      Cb      inner-back corner on the seam plane
    The ridge A1-A2-Cf is the crease you see down the middle of each piece.
    """
    b, c, w = p["half_w"], p["half_d"], p["tip_w"]
    n = math.hypot(b, c)
    axis = np.array([0.0, b / n, c / n])
    perp = np.array([0.0, -c / n, b / n])          # down-front, perpendicular to the axis
    L = (b * n - w * c / 2.0) / b                   # so the upper tip corner sits at y = b
    A1 = axis * L - perp * (w / 2.0)
    A2 = axis * L + perp * (w / 2.0)
    f = p["wing_frac"]
    Wp = np.array([b * f, b * (1 - f), 0.0])
    Wm = np.array([-b * f, b * (1 - f), 0.0])
    d, zd = p["inner_diag"]
    Dp = np.array([d, d, zd])
    Dm = np.array([-d, d, zd])
    Cf = np.array([0.0, p["inner_front"][0], p["inner_front"][1]])
    Cb = np.array([0.0, p["inner_back"], 0.0])
    return np.array([A1, A2, Wp, Wm, Dp, Dm, Cf, Cb])


def piece_transform(index):
    """Transform taking the top-front piece to piece `index` (0..7).
    0 top-front, 1 right-front, 2 bottom-front, 3 left-front, 4..7 the same at the back."""
    T = rot([0, 0, 1], -90 * (index % 4))
    if index >= 4:
        T = np.diag([1.0, 1.0, -1.0, 1.0]) @ T
    return T


def piece_raw(p):
    """Top-front piece: convex hull of the six corner points, shrunk a hair for the seams."""
    pts = piece_points(p)
    m = trimesh.points.PointCloud(pts).convex_hull
    m.apply_transform(scale_matrix(p["piece_gap"], m.centroid))
    return m


def _inside_hull(m, pts):
    """Point-in-convex-mesh test without extra dependencies."""
    origins = m.triangles[:, 0, :]
    normals = m.face_normals
    d = (pts[:, None, :] - origins[None, :, :]) @ normals.T  # wrong shape guard below
    d = np.einsum("pfk,fk->pf", pts[:, None, :] - origins[None, :, :], normals)
    return np.all(d <= 1e-6, axis=1)


def piece_axis(m):
    return unit(m.centroid)


def socket_range(p, m):
    """Where along the centroid ray the peg socket can live: (entry radius, end radius)."""
    ax = piece_axis(m)
    rs = np.arange(20.0, 120.0, 0.25)
    inside = _inside_hull(m, rs[:, None] * ax[None, :])
    if not inside.any():
        raise RuntimeError("centroid ray misses the piece")
    r_in = float(rs[inside][0])
    r_out = float(rs[inside][-1])
    return r_in, r_out


def fin(p):
    """One shell piece (top-front orientation) with the pin socket and spring counterbore
    bored along the centroid ray."""
    m = piece_raw(p)
    r_in, r_out = socket_range(p, m)
    depth = min(p["fin_socket_depth"], (r_out - r_in) - 3.0)
    ax = piece_axis(m)
    seat_d = p["spring_seat_depth"]
    sock = cyl_along(ax, p["fin_socket_r"], r_in - 1.0, r_in + seat_d + depth)
    seat = cyl_along(ax, p["spring_od"] / 2.0 + 0.3, r_in - 1.0, r_in + seat_d)
    return difference(m, [sock, seat])


def shell_offset(p, open_frac: float) -> float:
    """How far (mm) each piece sits out along its ray from the modelled position:
    closed_gap minus the built-in ~3 mm, plus travel * open_frac."""
    m = piece_raw(p)
    r_in, _ = socket_range(p, m)
    base_gap = r_in - p["core_r"]
    return (p["closed_gap"] - base_gap) + p["shell_travel"] * open_frac


def fin_printable(p):
    """The piece for printing: its largest flat face on the bed."""
    m = fin(p)
    raw = piece_raw(p)
    i = int(np.argmax(raw.area_faces))
    nrm = raw.face_normals[i]
    m.apply_transform(np.linalg.inv(align_z_to(-nrm)))   # face normal -> -z (face down)
    m.apply_translation(-m.bounds[0])
    return m


def fins_in_place(p, open_frac: float = 0.0):
    """All 8 pieces placed on the assembled Ghost (world frame), shell closed (0) .. open (1)."""
    base = fin(p)
    base.apply_translation(piece_axis(piece_raw(p)) * shell_offset(p, open_frac))
    out = []
    for i in range(8):
        m = base.copy()
        m.apply_transform(piece_transform(i))
        out.append(m)
    return out


def slider_pin(p):
    """Pin that carries a shell piece through the core's guide tube.  Print 8, vertical."""
    m = piece_raw(p)
    r_in, _ = socket_range(p, m)
    cap_r0 = p["core_r"] - p["core_wall"] - p["sleeve_len"] - p["shell_travel"] - 2.0  # cap radius (closed)
    tip_r = p["core_r"] + p["closed_gap"] + p["spring_seat_depth"] + p["fin_socket_depth"] - 1.0  # socket bottom (closed)
    length = tip_r - cap_r0
    pin = cylinder(radius=p["pin_r"], height=length, sections=48)
    pin.apply_translation([0, 0, length / 2.0])
    cap = cylinder(radius=p["pin_cap_r"], height=p["pin_cap_t"], sections=48)
    cap.apply_translation([0, 0, -p["pin_cap_t"] / 2.0])
    hole = cyl_along([1, 0, 0], 0.8, -10, 10)           # tendon hole through the cap
    hole.apply_translation([0, 0, -p["pin_cap_t"] / 2.0])
    m = pin.union(cap).difference(hole)
    m.apply_translation([0, 0, p["pin_cap_t"]])
    return m


def spider_ring(p):
    """The eight tendons tie to this ring; the Bowden wire pulls it backward along the eye axis."""
    m = cylinder(radius=p["ring_r"], height=p["ring_t"], sections=64)
    m.apply_translation([0, 0, p["ring_t"] / 2.0])
    holes = [cylinder(radius=1.3, height=10, sections=16)]           # wire knot / crimp
    for i in range(8):
        a = i * math.pi / 4 + math.pi / 8
        h = cylinder(radius=0.9, height=10, sections=12)
        h.apply_translation([p["ring_tie_r"] * math.cos(a), p["ring_tie_r"] * math.sin(a), 0])
        holes.append(h)
    return difference(m, holes)


def shell_servo_mount(p):
    """Bracket for the shell servo in the base: MG90S lies on its side (shaft along +x), the
    spool sits on the shaft, and a post 22 mm out holds the end of the Bowden sheath in line
    with the spool rim so the wire runs straight."""
    sb = p["servo_body"]
    blk = box(extents=[16.0, sb[0] + 6.0, sb[1] + 8.0])
    blk.apply_translation([-8.0, 0, (sb[1] + 8.0) / 2.0])
    pocket = box(extents=[sb[1] + 0.4, sb[0], 40.0])              # body slides in from the top
    pocket.apply_transform(rot([0, 1, 0], 90))
    pocket.apply_translation([-8.0 + 0.0, 0, (sb[1] + 8.0) / 2.0 + 4.0 + 20.0 - 4.0])
    # simpler: an open-top cradle: cut a channel the width of the body through the block
    chan = box(extents=[sb[1] + 0.4, sb[0] + 0.4, 40.0])
    chan.apply_translation([-8.0, 0, 4.0 + 20.0])
    tabs = []
    for sy in (1, -1):
        t = cylinder(radius=p["servo_hole_r"], height=30, sections=16)
        t.apply_transform(rot([0, 1, 0], 90))
        t.apply_translation([-8.0, sy * p["servo_hole_spacing"] / 2.0, 4.0 + sb[1] / 2.0])
        tabs.append(t)
    foot = box(extents=[52.0, sb[0] + 6.0, 3.0]); foot.apply_translation([10.0, 0, 1.5])
    post = box(extents=[8.0, 10.0, 4.0 + sb[1] / 2.0 + p["spool_r"] + 3.0])
    post.apply_translation([32.0, 0, post.extents[2] / 2.0])
    sheath = cylinder(radius=p["sheath_r"], height=6.0, sections=24)
    sheath.apply_transform(rot([0, 1, 0], 90))
    sheath.apply_translation([32.0 + 1.0, 0, 4.0 + sb[1] / 2.0 + p["spool_r"]])
    wire = cylinder(radius=1.2, height=20.0, sections=16)
    wire.apply_transform(rot([0, 1, 0], 90))
    wire.apply_translation([32.0 - 4.0, 0, 4.0 + sb[1] / 2.0 + p["spool_r"]])
    screws = []
    for sx in (-8.0, 28.0):
        for sy in (1, -1):
            s = cylinder(radius=1.7, height=10, sections=16)
            s.apply_translation([sx + 12.0, sy * (sb[0] / 2.0 + 1.0), 1.5]); screws.append(s)
    m = union([blk, foot, post])
    return difference(m, [chan, sheath, wire] + tabs + screws)


def ring_travel(p):
    """Solve for the ring's open/closed positions on the eye axis such that fixed-length
    tendons are taut in both states for the front group and the back group.
    Returns (z_open, z_closed, L_front, L_back)."""
    from scipy.optimize import fsolve
    R, wall = p["core_r"], p["core_wall"]
    cap_open = R - wall - p["sleeve_len"] - p["pin_cap_t"] / 2.0
    cap_closed = cap_open - p["shell_travel"]
    d = unit(piece_raw(p).centroid)                 # top-front ray
    tie = np.array([0.0, p["ring_tie_r"], 0.0])     # tie point on the ring, same azimuth
    def L(cap_r, z, back):
        c = d * cap_r
        if back: c = c * np.array([1, 1, -1])
        return np.linalg.norm(c - (tie + [0, 0, z]))
    def eqs(v):
        z0, z1 = v
        return [L(cap_open, z0, False) - L(cap_closed, z1, False),
                L(cap_open, z0, True) - L(cap_closed, z1, True)]
    z0, z1 = fsolve(eqs, [-10.0, -20.0])
    return float(z0), float(z1), float(L(cap_open, z0, False)), float(L(cap_open, z0, True)), cap_open, cap_closed


def spool(p):
    """Tendon spool for the shell servo: sits on a stock 20 mm round horn."""
    base_h = 3.0
    base_d = cylinder(radius=p["spool_r"] + 4.0, height=base_h, sections=64)   # sits on the horn
    base_d.apply_translation([0, 0, base_h / 2.0])
    horn = cylinder(radius=10.3, height=1.8, sections=64)      # pocket for the round horn
    horn.apply_translation([0, 0, 0.9])
    body = cylinder(radius=p["spool_r"], height=p["spool_t"], sections=64)
    body.apply_translation([0, 0, base_h + p["spool_t"] / 2.0])
    top = cylinder(radius=p["spool_r"] + 3.0, height=1.5, sections=64)
    top.apply_translation([0, 0, base_h + p["spool_t"] - 0.75])
    m = union([base_d, body, top])
    holes = [cylinder(radius=2.2, height=20, sections=24)]      # horn screw
    for i in range(8):
        h = cylinder(radius=0.9, height=20, sections=16)
        h.apply_translation([(p["spool_r"] - 1.8) * math.cos(i * math.pi / 4),
                             (p["spool_r"] - 1.8) * math.sin(i * math.pi / 4), 0])
        holes.append(h)
    return difference(m, [horn] + holes)


def peg_dirs(p):
    """Centroid rays of the 8 pieces - the core pegs point along these."""
    m = piece_raw(p)
    return [unit(trimesh.transform_points([m.centroid], piece_transform(i))[0]) for i in range(8)]


def core_halves(p):
    """Front and back hemispheres of the core, with pegs, eye bore, lip."""
    R, wall = p["core_r"], p["core_wall"]
    sphere = icosphere(subdivisions=4, radius=R)
    cavity = icosphere(subdivisions=4, radius=R - wall)
    def pegs(front: bool):
        """Guide tubes for the slider pins: from inside the cavity out to the surface."""
        dirs = [d for d in peg_dirs(p) if (d[2] > 0) == front]
        return [cyl_along(d, p["sleeve_or"], R - wall - p["sleeve_len"], R - 0.5) for d in dirs]

    def bores(front: bool):
        dirs = [d for d in peg_dirs(p) if (d[2] > 0) == front]
        return [cyl_along(d, p["sleeve_r"], R - wall - p["sleeve_len"] - 1.0, R + 2.0) for d in dirs]

    big = box(extents=[4 * R, 4 * R, 2 * R])
    front_keep = big.copy(); front_keep.apply_translation([0, 0, R])
    back_keep = big.copy(); back_keep.apply_translation([0, 0, -R])

    # ---- front half
    front = union([sphere] + pegs(True))
    front = front.intersection(front_keep)
    bore = cylinder(radius=p["eye_bore_r"], height=R, sections=96)
    bore.apply_translation([0, 0, R])
    screw_holes = []
    for a in (90, 210, 330):
        sh = cyl_along([math.cos(math.radians(a)), math.sin(math.radians(a)), 0],
                       1.1, R - wall - p["lip_h"], R + 1)
        sh.apply_translation([0, 0, p["lip_h"] / 2.0])
        screw_holes.append(sh)
    front = difference(front, [cavity, bore] + screw_holes + bores(True))

    # ---- back half
    back = union([sphere] + pegs(False))
    back = back.intersection(back_keep)
    back = back.difference(cavity)
    # Bowden wire passes from the neck socket straight into the cavity along the eye axis
    bowden = cylinder(radius=p["bowden_r"], height=30.0, sections=32)
    bowden.apply_translation([0, 0, -(R - wall) - 8.0])
    lip_o = cylinder(radius=R - wall - 0.3, height=p["lip_h"], sections=96)
    lip_o.apply_translation([0, 0, p["lip_h"] / 2.0])
    foot = cylinder(radius=R - 1.0, height=3.0, sections=96)      # overlaps the wall
    foot.apply_translation([0, 0, -1.5])
    lip_i = cylinder(radius=R - wall - 2.5, height=p["lip_h"] + 8, sections=96)
    lip = lip_o.union(foot).difference(lip_i)
    back = back.union(lip)
    # pilot holes in the lip for the 3 screws
    pilots = []
    for a in (90, 210, 330):
        ph = cyl_along([math.cos(math.radians(a)), math.sin(math.radians(a)), 0],
                       0.8, R - wall - 3.0, R)
        ph.apply_translation([0, 0, p["lip_h"] / 2.0])
        pilots.append(ph)
    # neck mount pad: a flat boss on the back pole with a socket for the head-mount stub
    pad = cylinder(radius=14.0, height=8.0, sections=64)        # face at z = -(R+5)
    pad.apply_translation([0, 0, -(R + 5.0) + 4.0])
    back = back.union(pad)
    stub_sock = cylinder(radius=6.3, height=8.0, sections=48)   # 8 mm deep socket
    stub_sock.apply_translation([0, 0, -(R + 5.0) + 4.0])
    # cable exit right next to the neck
    cable = cyl_along([0, -0.35, -1], 4.5, R - wall - 8, R + 8)
    back = difference(back, pilots + [stub_sock, cable, bowden] + bores(False))
    # 4 mic/vent holes on top of the back half
    vents = [cyl_along([0.15 * i, 0.75, -0.6], 1.3, R - wall - 2, R + 2) for i in (-2, -1, 1, 2)]
    back = difference(back, vents)

    # print orientation: flat faces on the bed
    front_p = front.copy()
    front_p.apply_transform(rot([1, 0, 0], 180))   # cut face down, eye up
    front_p.apply_translation([0, 0, -front_p.bounds[0][2]])
    back_p = back.copy()
    back_p.apply_translation([0, 0, -back_p.bounds[0][2]])  # lip up
    return front, back, front_p, back_p
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

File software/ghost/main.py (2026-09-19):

"""Ghost main loop.

    IDLE --(wake word)--> LISTENING --(silence)--> THINKING --(first sentence)--> SPEAKING
      ^                                                                              |
      +---------------- (follow-up window if the Ghost asked a question) -------------+

Run on the Pi:      python -m ghost.main
Desktop / no mic:   python -m ghost.main --sim          (type instead of talk)
No API key yet:     python -m ghost.main --sim --mock   (canned brain, tests the body)
"""
from __future__ import annotations

import argparse
import logging
import queue
import random
import signal
import sys
import threading
import time

from .config import CONFIG
from .personality import TIMER_LINES, WAKE_ACKS
from .tools import TimerBook, ToolBox

log = logging.getLogger("ghost")


class MockBrain:
    """Stand-in for Brain when there is no API key: exercises the whole pipeline."""
    lines = [
        "[curious] Say that again, Guardian? [happy] Kidding. I heard you. This is a test of my voice and my eye.",
        "[thinking] Let me think about that. [excited] Got it! The answer is forty-two, obviously.",
        "[worried] I don't have a link to the Tower yet, so I'm running on canned lines. [smug] Still charming though.",
    ]
    def reply(self, text):
        from .brain import _StreamParser
        p = _StreamParser()
        yield from p.feed(random.choice(self.lines)); yield from p.flush()
    def forget(self): pass


class Ghost:
    def __init__(self, sim: bool, mock: bool):
        from .eye import Eye
        from .lights import Ring
        from .motion import Body
        from .tts import Voice
        from .audio import Speaker

        self.sim = sim
        self.eye = Eye(); self.eye.start()
        self.ring = Ring(); self.ring.start()
        self.body = Body(); self.body.start()
        self.speaker = Speaker()
        self.voice = None
        try:
            self.voice = Voice()
        except Exception as e:
            log.warning("no TTS voice (%s) - replies will be printed only", e)

        self.timers = TimerBook(on_fire=self._timer_fired)
        self.tools = ToolBox(self.timers, set_volume=lambda v: setattr(self.speaker, "volume", v))
        if mock:
            self.brain = MockBrain()
        else:
            from .brain import Brain
            self.brain = Brain(self.tools)

        self.mic = self.wake = self.stt = None
        if not sim:
            from .audio import Mic
            from .wake import WakeWord
            from .stt import Transcriber
            self.mic = Mic(); self.mic.start()
            self.wake = WakeWord()
            self.stt = Transcriber()

        self._speech_q: "queue.Queue[tuple[str, str] | None]" = queue.Queue()
        self._speaking = threading.Event()
        self._interrupt = threading.Event()
        self._stop = threading.Event()
        threading.Thread(target=self._speaker_loop, daemon=True, name="speaker").start()
        self.mood("neutral")

    # ------------------------------------------------------------------
    def mood(self, m: str):
        self.eye.set(mood=m); self.ring.set(mood=m); self.body.mood(m)

    def say(self, text: str, emotion: str = "neutral"):
        self._speech_q.put((text, emotion))

    def _speaker_loop(self):
        """Synthesize + play sentences in order; the eye follows the audio level."""
        while not self._stop.is_set():
            item = self._speech_q.get()
            if item is None:
                continue
            text, emotion = item
            print(f"  Ghost [{emotion}]: {text}")
            if self.voice is None:
                time.sleep(min(3.0, 0.05 * len(text))); continue
            self._speaking.set()
            try:
                audio, rate = self.voice.synth(text)
                self.eye.set(mood="speaking"); self.ring.set(mood="speaking")
                meter = threading.Thread(target=self._meter, daemon=True); meter.start()
                self.speaker.play(audio, rate)
            except Exception as e:
                log.error("speech failed: %s", e)
            finally:
                self._speaking.clear()
                if self._speech_q.empty():
                    self.eye.set(mood=emotion or "neutral"); self.ring.set(mood=emotion or "neutral")

    def _meter(self):
        while self.speaker.playing.is_set():
            lvl = min(1.0, self.speaker.level * 6.0)
            self.eye.set(level=lvl); self.ring.set(level=lvl)
            time.sleep(0.03)
        self.eye.set(level=0.0); self.ring.set(level=0.0)

    def _wait_for_speech_done(self):
        while not self._speech_q.empty() or self._speaking.is_set():
            time.sleep(0.05)

    def _timer_fired(self, label: str):
        self.speaker.chime("done")
        line = random.choice(TIMER_LINES).format(label=label)
        from .brain import _StreamParser
        p = _StreamParser()
        for c in list(p.feed(line)) + list(p.flush()):
            if c.kind == "emotion": self.mood(c.emotion)
            elif c.kind == "speech": self.say(c.text, c.emotion)

    # ------------------------------------------------------------------
    def handle(self, text: str) -> bool:
        """Send text to the brain and speak the reply.  Returns True if the reply asked a question."""
        if not text.strip():
            return False
        low = text.lower().strip(" .!?")
        if low in ("never mind", "nevermind", "cancel", "stop"):
            self.mood("neutral"); return False
        if low in ("forget everything", "new conversation", "reset"):
            self.brain.forget(); self.say("Fresh start, Guardian.", "happy"); return False
        self.mood("thinking")
        asked = False
        last_emotion = "neutral"
        for chunk in self.brain.reply(text):
            if chunk.kind == "emotion":
                last_emotion = chunk.emotion
                self.mood(chunk.emotion)
            elif chunk.kind == "speech":
                self.say(chunk.text, chunk.emotion or last_emotion)
                asked = chunk.text.rstrip().endswith("?")
            elif chunk.kind == "tool":
                self.eye.set(mood="thinking"); self.ring.set(mood="thinking")
        self._wait_for_speech_done()
        return asked

    # ------------------------------------------------------------------
    def run_sim(self):
        print("Ghost sim. Type to talk (Ctrl-C to quit). Eye frames -> /tmp/ghost_eye.png unless a display is attached.")
        while not self._stop.is_set():
            try:
                text = input("\nYou: ")
            except (EOFError, KeyboardInterrupt):
                break
            self.handle(text)
            self.mood("neutral")
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

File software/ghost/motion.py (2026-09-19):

"""Pan/tilt gestures and the spreading shell, through a PCA9685 servo driver (I2C).

Gestures are tiny scripted moves with easing, run on a background thread so they never
block speech.  Tilt is clamped to +-tilt_range: the printed arm clears +-15 degrees with
the shell open or closed.

The shell servo winds eight tendons onto a spool: winding pulls the pieces in against
their springs (closed), unwinding lets the springs spread the shell open like the Ghost's
scan animation.  `shell(0..1)` sets how open it is.
"""
from __future__ import annotations

import logging
import math
import random
import threading
import time

from .config import CONFIG

log = logging.getLogger("ghost.motion")


class Body(threading.Thread):
    def __init__(self):
        super().__init__(daemon=True, name="motion")
        self.kit = None
        self._q: list[tuple[str, float]] = []
        self._lock = threading.Lock()
        self._stop = threading.Event()
        self.pan, self.tilt = 0.0, 0.0            # degrees from centre
        self.open = 0.0                           # shell: 0 closed .. 1 fully open
        if CONFIG.servos:
            try:
                from adafruit_servokit import ServoKit
                self.kit = ServoKit(channels=16)
                for ch in (CONFIG.servo_pan_ch, CONFIG.servo_tilt_ch, CONFIG.servo_shell_ch):
                    self.kit.servo[ch].set_pulse_width_range(500, 2500)
                self._write(0, 0)
                self._write_shell(0.0)
                log.info("servos ready on PCA9685")
            except Exception as e:
                log.warning("no servos (%s)", e)

    # ------------------------------------------------------------------
    def gesture(self, name: str, strength: float = 1.0):
        with self._lock:
            self._q.append((name, strength))

    def mood(self, emotion: str):
        """Map an emotion tag to body language (head move + how open the shell sits)."""
        table = {
            "happy": "bounce", "excited": "wiggle", "curious": "tilt_curious", "thinking": "look_up",
            "worried": "shrink", "sad": "droop", "surprised": "recoil", "annoyed": "shake",
            "smug": "tilt_curious", "sleepy": "droop", "listening": "lean_in", "neutral": "center",
        }
        g = table.get(emotion)
        if g:
            self.gesture(g)
        shell = {
            "listening": 0.6, "thinking": 1.0, "excited": 1.0, "surprised": 1.0, "curious": 0.5,
            "happy": 0.4, "speaking": 0.3, "smug": 0.3, "neutral": 0.0, "worried": 0.0,
            "sad": 0.0, "annoyed": 0.0, "sleepy": 0.0, "offline": 0.0,
        }
        if emotion in shell:
            self.shell(shell[emotion])

    def shell(self, open_frac: float, dur: float = 0.5):
        """Spread the shell: 0 = closed, 1 = fully open.  Eased on the motion thread."""
        with self._lock:
            self._q.append(("shell", max(0.0, min(1.0, open_frac)), dur))

    # ------------------------------------------------------------------
    def _write(self, pan: float, tilt: float):
        pan = max(-CONFIG.pan_range, min(CONFIG.pan_range, pan))
        tilt = max(-CONFIG.tilt_range, min(CONFIG.tilt_range, tilt))
        self.pan, self.tilt = pan, tilt
        if self.kit:
            try:
                self.kit.servo[CONFIG.servo_pan_ch].angle = CONFIG.pan_center + pan
                self.kit.servo[CONFIG.servo_tilt_ch].angle = CONFIG.tilt_center + tilt
            except Exception as e:
                log.debug("servo write failed: %s", e)

    def _write_shell(self, open_frac: float):
        self.open = max(0.0, min(1.0, open_frac))
        if self.kit:
            try:
                a = CONFIG.shell_closed_angle + (CONFIG.shell_open_angle - CONFIG.shell_closed_angle) * self.open
                self.kit.servo[CONFIG.servo_shell_ch].angle = a
            except Exception as e:
                log.debug("shell servo write failed: %s", e)

    def _move_shell(self, target: float, dur: float):
        o0 = self.open
        steps = max(2, int(dur * 50))
        for i in range(1, steps + 1):
            s = i / steps
            s = s * s * (3 - 2 * s)
            self._write_shell(o0 + (target - o0) * s)
            time.sleep(dur / steps)
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

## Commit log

2026-09-19 Destiny Ghost: printable STLs, hardware plans and voice companion software
    - hardware/generate_stl.py: parametric trimesh generator for the 8 shell fins,
    core halves, eye bezel, pan/tilt arm, head mount, base and lid. Checks fin/fin,
    fin/core and tilt-sweep collisions. Exported STLs plus preview renders included.
    - docs/: bill of materials, print guide, wiring/pin map, assembly, Pi setup,
    voice and personality notes.
    - software/ghost: wake word (openWakeWord), STT (faster-whisper), Claude brain
    with streaming, emotion tags and local tools, Piper TTS with a Ghost filter,
    GC9A01 eye animation, NeoPixel ring, PCA9685 pan/tilt gestures, sim/mock modes,
    install script and systemd unit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
    [arm.stl, base.stl, base_lid.stl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]
2026-09-19 Rebuild the shell pieces to match the reference sheet
    Each of the 8 pieces is now the convex hull of points read off the Bungie
    concept sheet: a 40 mm blunt tip edge, wings on the diamond edge midpoints,
    shared inner corners on the diagonals at the eye ring, and a ridge down the
    middle. This reproduces the sheet in all three views: the diamond with thin X
    seams from the front, the X with blunt arm ends from the side, and the central
    diamond with side notches from the top. Proportions are 180 wide/tall by
    157 deep. The core, pegs, arm, base and docs are updated to suit, and the
    generator now checks piece/piece, piece/core+bezel and tilt-sweep collisions.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
    [arm.stl, base.stl, base_lid.stl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]
2026-09-19 Make the shell spread open like the in-game scan
    Each shell piece now rides a slider pin through a guide tube in the core. A
    compression spring on the pin pushes the piece outward; a fishing-line tendon
    from the pin's inner cap ties to a spider ring on the eye axis. A Bowden cable
    runs from the ring through the hollow neck and arm to a spool on a third
    servo in the base. Winding the spool pulls all eight pieces closed; releasing
    it lets the shell spring open 12 mm along each piece's own axis.
    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
    [arm.stl, base_lid.stl, core_back.stl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]
2026-09-19 Shaded renders and tighter closed shell
    hardware/render.py: a small numpy z-buffer rasterizer (perspective camera,
    smooth normals, three Blinn-Phong lights, metallic pieces with per-pixel gold
    tips, emissive eye with bloom, floor shadow) that renders the assembled Ghost
    closed, open and as a four-view turnaround into docs/renders/.
    The compressed spring now sits in a 6 mm counterbore inside each piece, so the
    closed shell keeps the reference's 3 mm seams instead of standing 8 mm off the
    core. README uses the new renders.
    Claude-Session: https://claude.ai/code/session_01SYpD3C71dU6dxCAi9bwTmm
    [fin_x8.stl, slider_pin_x8.stl]
2026-11-10 Reel: render pipeline and look stills for the teaser
    Loads the 12 STLs, places them with generate_stl.py's transforms (verified
    against the generator), and renders the assembled Ghost closed and open in a
    three.js studio scene: brushed silver shell, matte black structure, glowing
    bezel, eye shader ported from eye.py.
    Claude-Session: https://claude.ai/code/session_01NCmouBxUu5VMpQ8bVSWZ3F
2026-11-10 Reel: hexagon iris reads, visible springs, lighter shell, eye close-up still
    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
2026-11-10 Reel: full 14-bar timeline, build props, text overlay, voice and render script
    Print macro, exploded build, dark bar, drop, three chat demos and end card,
    all cut to 110 BPM. Voice lines use the project's Piper voice and ghost_fx.
    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
2026-11-10 Reel: final 30 s cut, clean and beat-marked MP4s
    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
2026-11-12 Darksaber reel: 2D line-art build, 3D ignition, synthesised sound
    Source for an 11.5 s Instagram teaser built from the Darksaber LED blade
    project's STLs. Video is rendered separately.
    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
2026-11-12 Darksaber reel: final 11.5 s cut with sound
    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
2026-11-12 Darksaber reel: leave headroom on the sound track
    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
2026-11-12 Darksaber reel: add a 3D shot of the printed pieces assembling
    The 2D assembly diagram now dissolves into the real parts snapping together,
    then the camera pushes into the emitter and the solder cut-away dissolves in.
    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
2026-11-12 Darksaber reel: 13.6 s cut with the 3D assembly shot
    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
2026-11-12 Darksaber reel: L-shaped guard matched to the printed hilt, ribbed pommel
    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
2026-11-12 Darksaber reel: close the hilt gaps (grip plugs into the emitter socket, guard arm seats on its rear face)
    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
